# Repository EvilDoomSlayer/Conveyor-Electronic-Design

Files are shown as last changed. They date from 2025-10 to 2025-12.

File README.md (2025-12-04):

# Conveyor-Electronic-Design

This repository contains the electronic design automation (EDA) files for the **Luggage Classification Conveyor** custom PCB. It is a submodule of the main firmware repository.

## Overview

This PCB consolidates the connections between the ESP32 microcontroller, the motor drivers, and the various sensors used in the sorting system. It replaces a breadboard setup to provide a robust and reliable connection for the sorting machinery.

## Project Contents

* **/KiCad_Project**: The full project folder containing:
    * `.kicad_sch`: The schematic file.
    * `.kicad_pcb`: The PCB layout file.
* **/Gerbers**: Production files generated for PCB fabrication (Zip file usually required by manufacturers like JLC or PCBWay).

## Schematic Details

The board is designed to interface with an **ESP32-WROOM-32** dev module.

### Key Interfaces
* **Power Input**: 5V DC (Powers the ESP32 and the Servos/DC Motor).
* **Motor Driver**: On-board socket for an **L293D** motor driver IC.
* **Sensor Headers**:
    * 3-pin headers for Servos (Signal, VCC, GND).
    * 4-pin header for HX711 (Load Cell Amplifier).
    * Digital headers for IR (E18-D80NK) and Magnetic (KY-024) sensors.

### Pinout Mapping
This PCB routes the ESP32 GPIOs strictly according to the firmware configuration:

| Component | ESP32 GPIO |
| :--- | :--- |
| **L293D (1A/2A)** | GPIO 16, 17 |
| **Load Cell (SCK/DT)** | GPIO 19, 23 |
| **Servos (1 & 2)** | GPIO 21, 22 |
| **Magnetic Sensor** | GPIO 32 |
| **IR Sensor** | GPIO 34 |

## Fabrication

The design is a 2-layer board. Standard manufacturing tolerances apply:
* **Thickness**: 1.6mm
* **Copper Weight**: 1oz
* **Solder Mask**: Green (or preferred color)

## Software Used

* **KiCad**: For Schematic capture and PCB Layout.

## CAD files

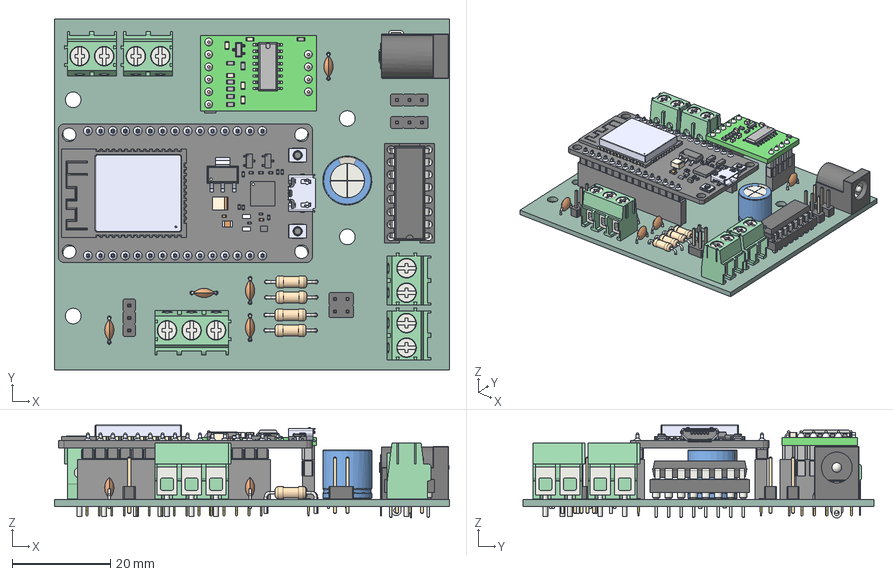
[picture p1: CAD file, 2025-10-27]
Conveyor/Conveyor.step
80.5 x 71.6 x 18.9 mm
PinHeader_1x03_P2.54mm_Vertical x 3
CP_Radial_D10.0mm_P5.00mm
BarrelJack_Horizontal
TerminalBlock_Phoenix_PT-1,5-3-5.0-H_1x03_P5.00mm_Horizontal
TerminalBlock_Phoenix_PT-1,5-2-5.0-H_1x02_P5.00mm_Horizontal x 4
C_Disc_D4.3mm_W1.9mm_P5.00mm x 5
ESP32-DEVKIT-V1
Pitch_x_15 x 2
Plastic_x_15 x 2
1x6 Male Header_001
1x4 Male Header_001
SOP-16L_001
1x4 Female Header_001
1x6 Female Header_001
0603 Resistor_001
0603 Capacitor_001
0603 Capacitor_002
0603 Capacitor_003
0603 Capacitor_004
0603 Capacitor_005
0603 Resistor_002
0603 Resistor_003
0603 Resistor_004
0603 Resistor_005
0603 Resistor_006
0603 Resistor_007
Surface Mount Transistor_001
Pitch_x_8 x 2
Plastic_x_8 x 2
R_Axial_DIN0207_L6.3mm_D2.5mm_P10.16mm_Horizontal x 4
PinHeader_2x02_P2.54mm_Vertical
DIP-16_W7.62mm_Socket
DIP-16_W7.62mm
Conveyor_PCB

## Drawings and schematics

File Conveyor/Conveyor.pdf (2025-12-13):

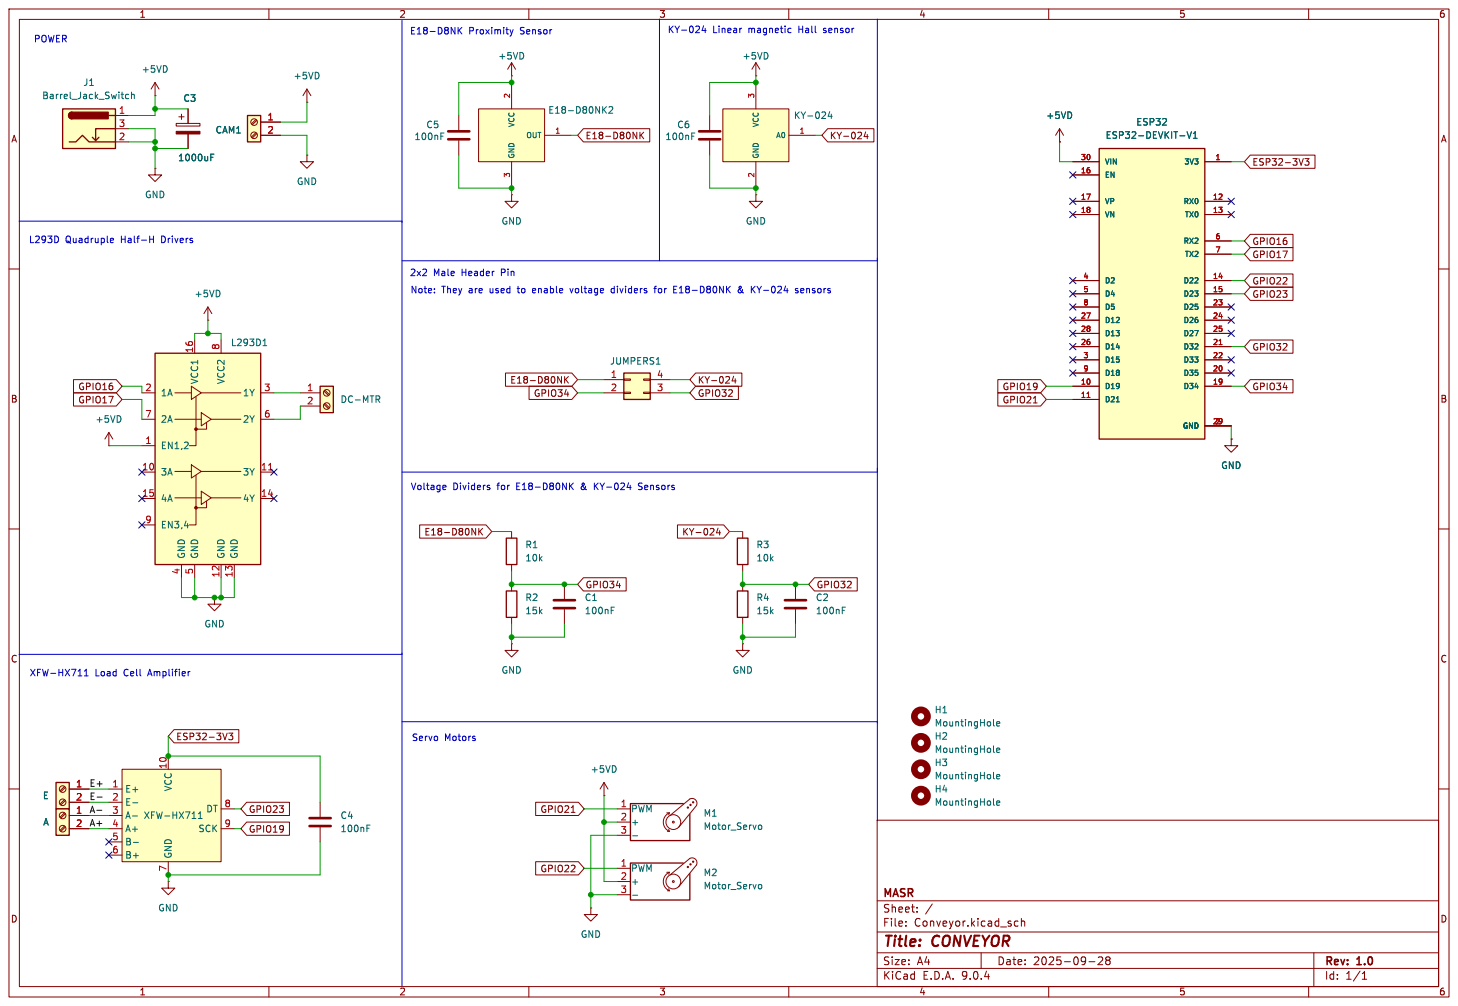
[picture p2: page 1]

File: Conveyor.kicad_sch Sheet: / MASR

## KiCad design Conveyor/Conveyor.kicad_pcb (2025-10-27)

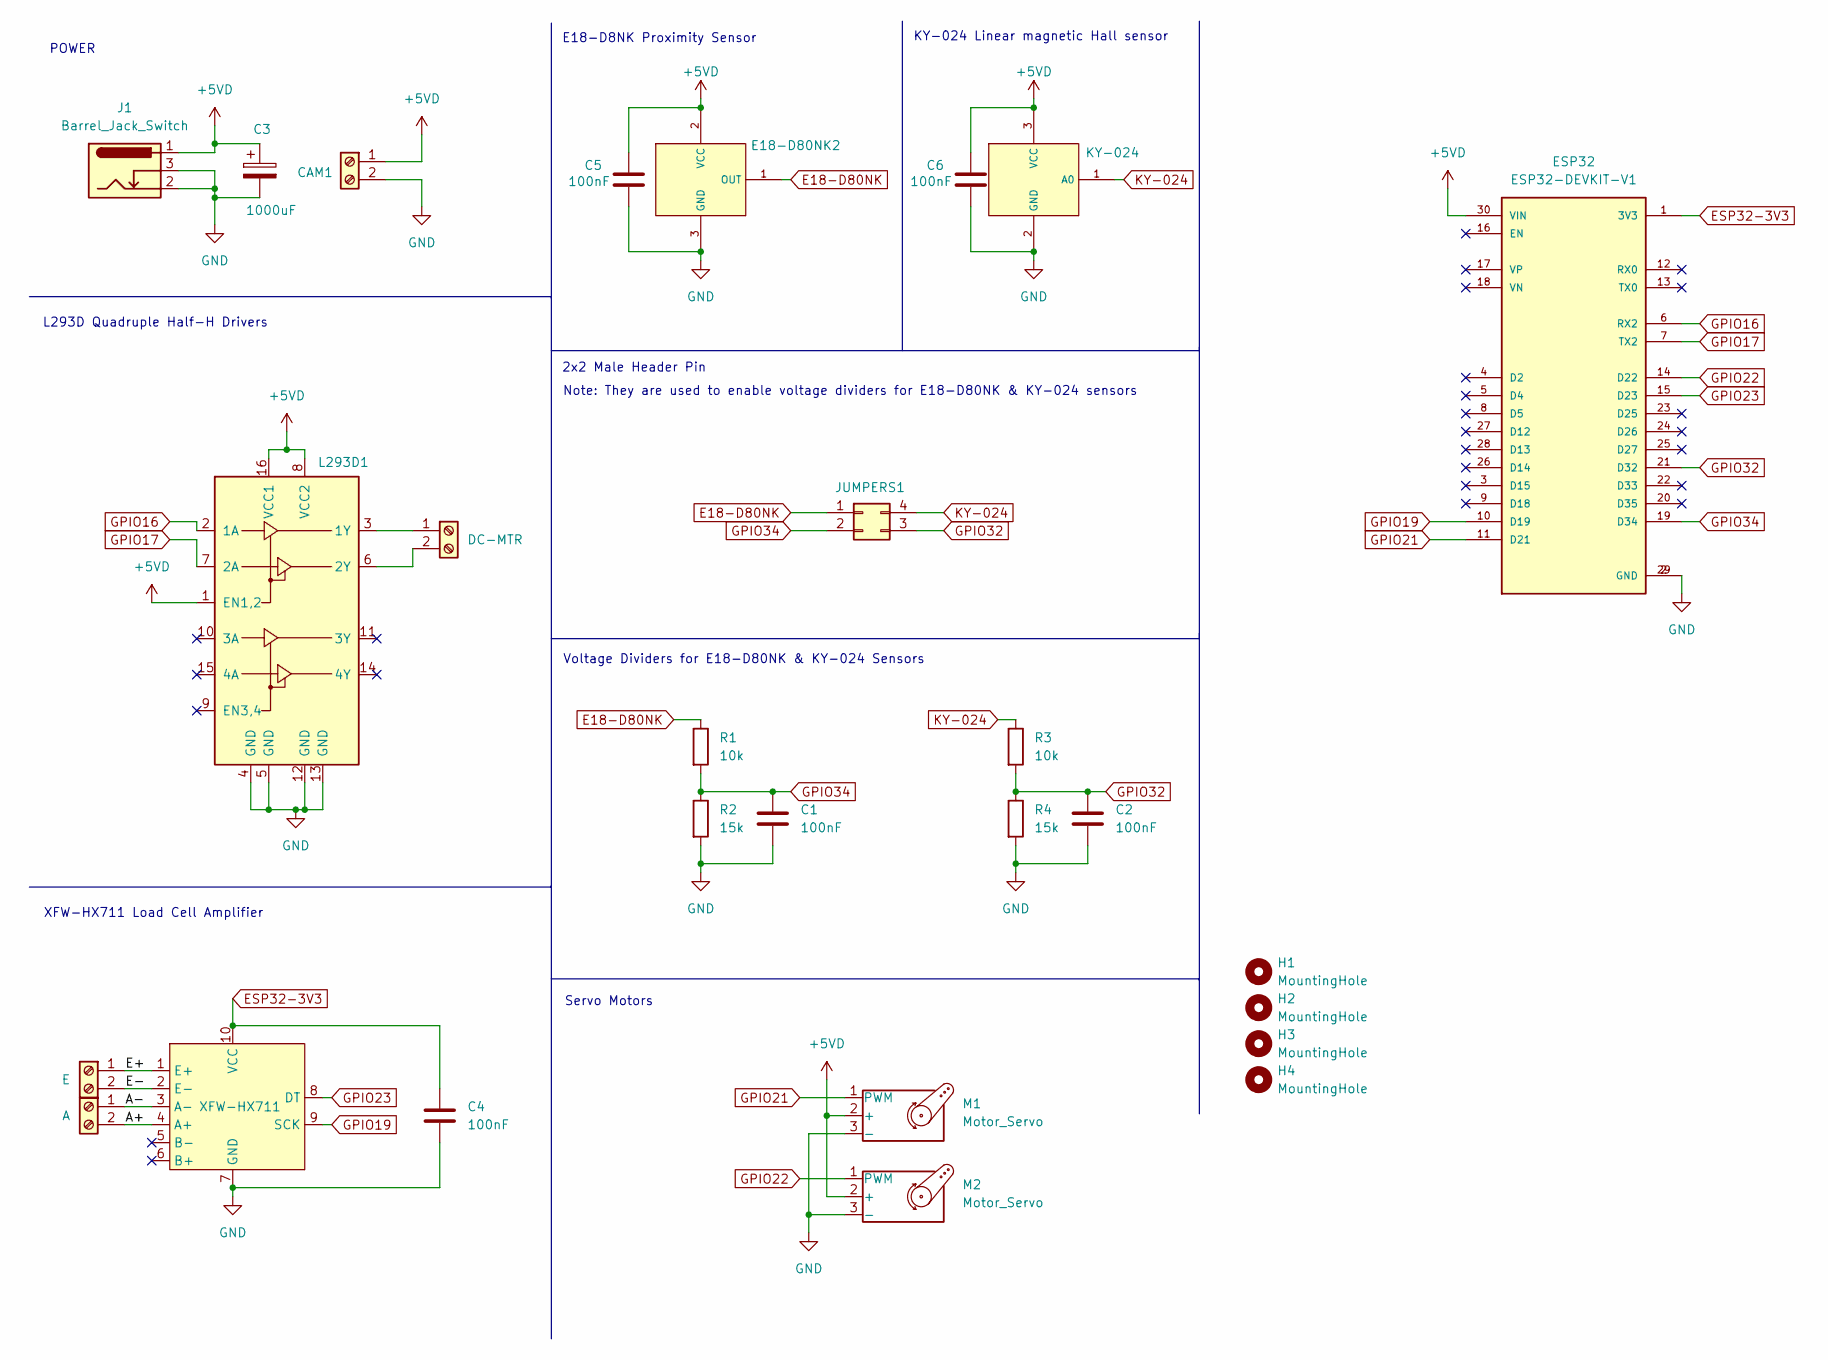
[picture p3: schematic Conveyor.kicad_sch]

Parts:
C1, C2, C4, C5, C6: 100nF; C_Disc_D4.3mm_W1.9mm_P5.00mm
C3: 1000uF; CP_Radial_D10.0mm_P5.00mm
CAM1: 5VCC; TerminalBlock_Phoenix_PT-1,5-2-5.0-H_1x02_P5.00mm_Horizontal
E18-D80NK2: E18-D80NK2; PinHeader_1x03_P2.54mm_Vertical
ESP32: ESP32-DEVKIT-V1; MODULE_ESP32_DEVKIT_V1; PARTREV N/A
H1, H2, H3, H4: MountingHole; MountingHole_3.2mm_M3
HX711-A1: A; TerminalBlock_Phoenix_PT-1,5-2-5.0-H_1x02_P5.00mm_Horizontal
HX711-E1: E; TerminalBlock_Phoenix_PT-1,5-2-5.0-H_1x02_P5.00mm_Horizontal
J1: Barrel_Jack_Switch; BarrelJack_Horizontal
JUMPERS1: Header 2x2; PinHeader_2x02_P2.54mm_Vertical
KY-024: KY-024; TerminalBlock_Phoenix_PT-1,5-3-5.0-H_1x03_P5.00mm_Horizontal
L293D1: H-BRIDGE; DIP-16_W7.62mm_Socket
M1, M2: Motor_Servo; PinHeader_1x03_P2.54mm_Vertical
MTR1: DC-MTR; TerminalBlock_Phoenix_PT-1,5-2-5.0-H_1x02_P5.00mm_Horizontal
R1, R3: 10k; R_Axial_DIN0207_L6.3mm_D2.5mm_P10.16mm_Horizontal
R2, R4: 15k; R_Axial_DIN0207_L6.3mm_D2.5mm_P10.16mm_Horizontal
XFW-HX711: HX711; XFW-HX711

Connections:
+5VD: C3.1, C5.1, C6.1, CAM1.1, E18-D80NK2.2 (VCC), ESP32.30 (VIN), J1.1, KY-024.3 (VCC), L293D1.1 (EN1,2), L293D1.8 (VCC2), L293D1.16 (VCC1), M1.2 (+), M2.2 (+)
/A+: HX711-A1.2, XFW-HX711.4 (A+)
/A-: HX711-A1.1, XFW-HX711.3 (A-)
/E+: HX711-E1.1, XFW-HX711.1 (E+)
/E-: HX711-E1.2, XFW-HX711.2 (E-)
E18-D80NK: E18-D80NK2.1 (OUT), JUMPERS1.1, R1.1
ESP32-3V3: C4.1, ESP32.1 (3V3), XFW-HX711.10 (VCC)
GND: C1.2, C2.2, C3.2, C4.2, C5.2, C6.2, CAM1.2, E18-D80NK2.3 (GND), ESP32.2 (GND), ESP32.29 (GND), J1.2, J1.3, KY-024.2 (GND), L293D1.4 (GND), L293D1.5 (GND), L293D1.12 (GND), L293D1.13 (GND), M1.3 (-), M2.3 (-), R2.2, R4.2, XFW-HX711.7 (GND)
GPIO16: ESP32.6 (RX2), L293D1.2 (1A)
GPIO17: ESP32.7 (TX2), L293D1.7 (2A)
GPIO19: ESP32.10 (D19), XFW-HX711.9 (SCK)
GPIO21: ESP32.11 (D21), M1.1 (PWM)
GPIO22: ESP32.14 (D22), M2.1 (PWM)
GPIO23: ESP32.15 (D23), XFW-HX711.8 (DT)
GPIO32: C2.1, ESP32.21 (D32), JUMPERS1.3, R3.2, R4.1
GPIO34: C1.1, ESP32.19 (D34), JUMPERS1.2, R1.2, R2.1
KY-024: JUMPERS1.4, KY-024.1 (A0), R3.1
unnamed: L293D1.3 (1Y), MTR1.1
unnamed: L293D1.6 (2Y), MTR1.2

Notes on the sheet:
E18-D8NK Proximity Sensor
L293D Quadruple Half-H Drivers
KY-024 Linear magnetic Hall sensor
POWER
Servo Motors
Note: They are used to enable voltage dividers for E18-D80NK & KY-024 sensors
Voltage Dividers for E18-D80NK & KY-024 Sensors
2x2 Male Header Pin
XFW-HX711 Load Cell Amplifier

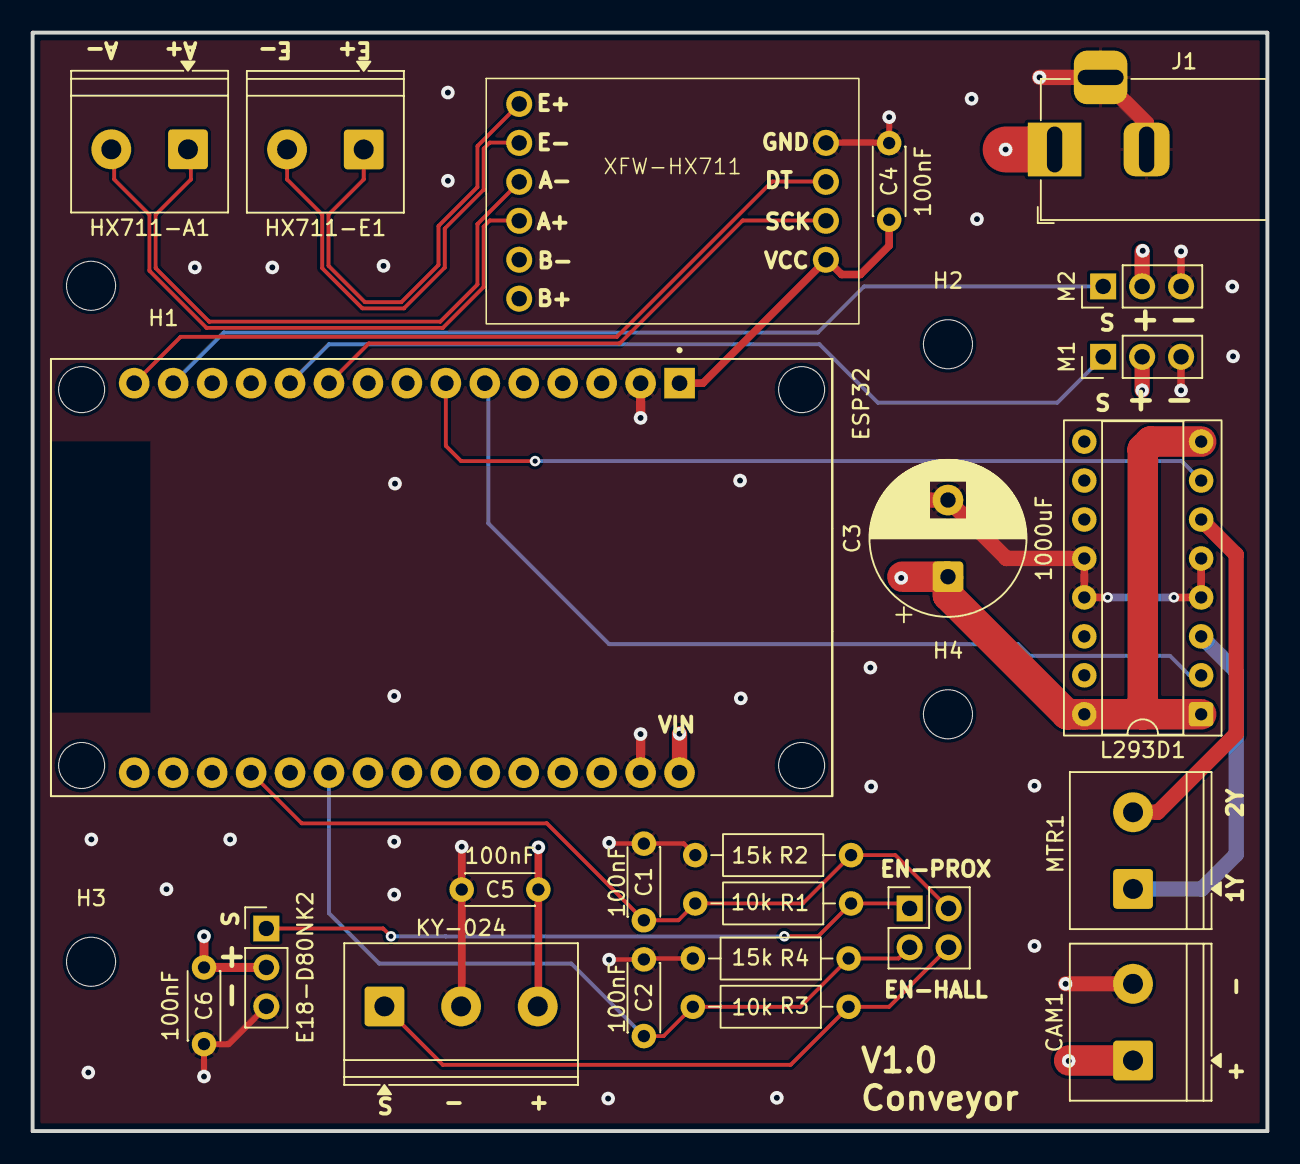
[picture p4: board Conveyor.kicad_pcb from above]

Board: 4 copper layers, 80.5 x 71.6 mm, 27 parts (0 on the bottom side), 19 nets.
